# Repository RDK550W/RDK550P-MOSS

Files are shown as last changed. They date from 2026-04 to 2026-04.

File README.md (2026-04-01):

# RDK550P-MOSS

基于 [D-Robotics RDK X5](https://developer.d-robotics.cc/rdk_doc/Quick_start/hardware_introduction/rdk_x5) 的桌面 AI 机器人伴侣。致敬《流浪地球》中的 MOSS。

它有眼睛（MIPI 摄像头）、能转头（双轴舵机云台）、能听你说话（语音唤醒 + ASR）、能跟你聊天（LLM 对话）、还会跳舞。

> **Agent 部署提示：** 如果你是 AI Agent 且需要在 RDK X5 上自动部署此项目，直接阅读 [`DEPLOY.md`](DEPLOY.md)，按步骤执行即可。

## 功能

- **语音交互** — 唤醒词激活，离线 VAD + SenseVoice ASR，edge-tts 语音回复
- **声纹识别** — 注册说话人后能识别"谁在说话"
- **说话人分离** — 多人对话场景下区分不同说话人
- **舵机控制** — 余弦缓动平滑运动，支持跳舞、环顾、点头等动作
- **音乐同步跳舞** — 节拍检测 + 编舞，跟着音乐节奏动
- **MIPI 摄像头** — 拍照、环境感知
- **LLM 大脑** — 通过 [OpenClaw](https://github.com/openclaw/openclaw) 接入 Claude/GPT 等模型，具备记忆、工具调用、定时任务等能力
- **守护进程** — systemd 管理，崩溃自动重启，开机自启

## 硬件清单

| 组件 | 型号 | 参考链接 | 备注 |
|---|---|---|---|
| 运算平台 | D-Robotics RDK X5 | [官方](https://developer.d-robotics.cc/) | 8TOPS BPU，ARM Cortex-A55 |
| 摄像头 | IMX477 MIPI 模组 | [购买](https://detail.tmall.com/item.htm?id=636204625264) | MIPI CSI 排线连接 |
| 舵机 x2 | PTK7465 数字舵机 | — | Yaw（左右）+ Pitch（上下） |
| USB 音频模块 | USB 麦克风+扬声器一体模块 | [购买](https://item.taobao.com/item.htm?id=909788853795) | 免驱，含麦克风和扬声器 |
| 云台支架 + 外壳 | SolidWorks 2024 3D 模型 | [`hardware/3d-model/`](hardware/3d-model/) | 含装配体 + 全部零件，3D 打印 |
| 供电 | 5V/3A USB-C | — | RDK X5 标准供电 |

详细物料清单和接线说明见 [`hardware/BOM.md`](hardware/BOM.md)

## 快速开始

### 前提

- RDK X5 已刷好官方系统（Ubuntu 22.04）
- 硬件已接线完成
- 有网络连接

### 部署

```bash
git clone https://github.com/RDK550W/RDK550P-MOSS.git
cd RDK550P-MOSS
sudo bash setup/install.sh
```

一键安装脚本会自动完成所有配置。详细分步说明见 [`DEPLOY.md`](DEPLOY.md)。

## 项目结构

```
RDK550P-MOSS/
├── DEPLOY.md                # Agent/人类 分步部署指南
├── README.md                # 项目介绍
├── LICENSE                  # MIT
├── hardware/
│   ├── BOM.md               # 物料清单 + 接线说明
│   └── 3d-model/            # SolidWorks 2024 外壳+云台模型
│       ├── RDK550W装配体.SLDASM
│       ├── 标准件/           # 舵机、舵盘参考模型
│       └── 零件库/           # 3D 打印零件 (P00~P12 + 支座)
├── voice-assistant/         # 语音助手（核心）
│   ├── voice_assistant.py   # 主程序
│   ├── speaker_id.py        # 声纹识别
│   ├── speaker_diarization.py  # 说话人分离
│   ├── enroll_speaker.py    # 声纹注册
│   ├── start.sh             # 启动脚本
│   ├── *.wav                # 音效文件（ding/dong/wake 等）
│   └── models/              # AI 模型 (gitignored, 由脚本下载)
├── scripts/                 # 工具脚本
│   ├── dance.py             # 舵机舞蹈（含 move_eased 标准实现）
│   ├── dance_jntm.py        # 音乐同步跳舞示例
│   ├── idle_motion.py       # 闲时随机动作
│   ├── snap.py              # MIPI 摄像头拍照
│   └── camera_test.py       # 摄像头测试
├── setup/                   # 安装脚本
│   ├── install.sh           # 一键安装
│   ├── download_models.sh   # 模型下载
│   ├── setup_alsa.sh        # ALSA 音频配置
│   ├── setup_pwm.sh         # PWM 舵机初始化
│   └── requirements.txt     # Python 依赖
├── openclaw-templates/      # OpenClaw 配置模板
│   ├── MEMORY.md.template   # 出厂记忆（技术经验、参数、踩坑教训）
│   ├── SOUL.md.template     # 机器人性格
│   ├── USER.md.template     # 主人信息
│   ├── IDENTITY.md.template # 机器人身份
│   ├── TOOLS.md.template    # 硬件备忘
│   ├── HEARTBEAT.md.template # 心跳任务
│   └── AGENTS.md.template   # 工作空间规则
├── systemd/                 # 系统服务
│   └── voice-assistant.service
├── tutorials/               # 详细教程
│   ├── rdk-x5-voice-assistant-tutorial.md
│   ├── rdk-x5-servo-pwm-tutorial.md
│   ├── rdk-x5-mipi-camera-tutorial.md
│   ├── rdk-x5-tts-tutorial.md
│   ├── rdk-x5-bpu-yolov5-tutorial.md
│   └── rdk-x5-gpio-tutorial.md
└── docs/
    ├── architecture.md      # 系统架构
    └── troubleshooting.md   # 踩坑指南
```

## 系统架构

```
┌──────────────────────────────────────────┐
│              OpenClaw (AI 大脑)            │
│  LLM 对话 · 记忆系统 · 定时任务 · 工具调用  │
└──────────────┬───────────────────────────┘
               │ openclaw agent CLI
┌──────────────▼───────────────────────────┐
│          Voice Assistant (守护进程)        │
│  Silero VAD → SenseVoice ASR → 3DSpeaker │
│  → OpenClaw Agent → edge-tts → aplay     │
└──────────────────────────────────────────┘
    │              │              │
┌───▼────┐  ┌─────▼──────┐  ┌───▼──────┐
│USB 音频 │  │ PTK7465 x2 │  │ IMX477   │
│麦克风+  │  │ 舵机云台    │  │ 摄像头    │
│扬声器   │  │ (PWM)      │  │ (MIPI)   │
└────────┘  └────────────┘  └──────────┘
```

详细架构说明见 [`docs/architecture.md`](docs/architecture.md)

## 自定义

- **唤醒词** — 修改 `voice_assistant.py` 中的唤醒词列表
- **TTS 声音** — 修改 edge-tts 的 voice 参数（`edge-tts --list-voices` 查看可用声音）
- **舞蹈动作** — 参考 `scripts/dance.py` 的 `move_eased()` 编写新动作
- **摄像头** — 结合 BPU 模型做目标检测等（参考 tutorials）
- **AI 人格** — 编辑 OpenClaw 的 `SOUL.md`

## 踩坑指南

详见 [`docs/troubleshooting.md`](docs/troubleshooting.md)

## 致谢

- [D-Robotics](https://developer.d-robotics.cc/) — RDK X5 硬件平台
- [OpenClaw](https://github.com/openclaw/openclaw) — AI Agent 运行时
- [sherpa-onnx](https://github.com/k2-fsa/sherpa-onnx) — 离线语音识别
- [SenseVoice](https://github.com/FunAudioLLM/SenseVoice) — ASR 模型
- [3D-Speaker](https://github.com/alibaba-damo-academy/3D-Speaker) — 声纹识别
- [edge-tts](https://github.com/rany2/edge-tts) — 文本转语音
- [Silero VAD](https://github.com/snakers4/silero-vad) — 语音活动检测

## License

MIT

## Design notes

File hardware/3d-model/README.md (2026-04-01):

# 3D 模型文件

RDK550W 外壳和云台支架的 3D 模型，使用 **SolidWorks 2024** 设计。

## 文件结构

```
3d-model/
├── RDK550W装配体.SLDASM      # 主装配体（打开这个看整体）
├── 标准件/                    # 标准件（舵机、舵盘等，仅参考）
│   ├── Servo_PTK7465.SLDPRT  # PTK7465 舵机模型
│   └── 舵盘.SLDPRT
└── 零件库/                    # 需要 3D 打印的零件
    ├── P00_安装卡扣.SLDPRT
    ├── P01_顶座.SLDPRT        # 摄像头顶座
    ├── P02_顶座上盖.SLDPRT
    ├── P03_机械臂1.SLDPRT     # 云台连接臂
    ├── P04_机械臂2.SLDPRT
    ├── P05_机械臂3.SLDPRT
    ├── P06_主体后壳_X5版.SLDPRT  # 主体后壳（RDK X5 适配版）
    ├── P06_主体后壳.SLDPRT       # 主体后壳（通用版）
    ├── P07_主体外挂.SLDPRT
    ├── P08_主体正盖.SLDPRT
    ├── P09_主体正盖侧灯.SLDPRT
    ├── P10_主体正盖面板01.SLDPRT
    ├── P11_主体正盖面板02.SLDPRT
    ├── P12_主体正盖外挂.SLDPRT
    ├── 支座A.SLDPRT
    ├── 支座B.SLDPRT
    └── 支座C.SLDPRT
```

## 打印建议

- 材料：PLA 或 PETG 均可
- 层高：0.2mm
- 填充：20~30%
- RDK X5 用户请使用 `P06_主体后壳_X5版.SLDPRT`

## 没有 SolidWorks？

如果没有 SolidWorks 2024，可以：
1. 用免费的 [eDrawings Viewer](https://www.edrawingsviewer.com/) 查看
2. 在线查看：上传到 [3DViewer.net](https://3dviewer.net/)
3. 如果需要 STL 格式，可以用 FreeCAD 转换，或提 Issue 我来导出

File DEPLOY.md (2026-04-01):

# DEPLOY.md — Agent 自动部署指南

> 本文件是给 AI Agent 读的。如果你是 Agent，按顺序执行以下步骤即可完成部署。
> 目标平台：D-Robotics RDK X5 (aarch64, Ubuntu 22.04)

## 前提条件

- 硬件已接线完成（参考 `hardware/BOM.md` 和 `hardware/3d-model/`）
- RDK X5 已刷好官方 Ubuntu 22.04 系统
- 有网络连接
- 当前用户是 root（或有 sudo 权限）

## Step 1: 安装系统依赖

```bash
apt-get update
apt-get install -y alsa-utils ffmpeg bc python3-pip python3-dev git wget curl
```

## Step 2: 安装 Python 依赖

```bash
pip3 install -i https://pypi.tuna.tsinghua.edu.cn/simple \
    sherpa-onnx==1.12.30 \
    edge-tts==7.2.7 \
    numpy==1.26.4 \
    opencv-python==4.11.0.86
```

> 注意：pyaudio 在此平台无法安装（缺少 portaudio19-dev），不需要装。音频采集用 arecord subprocess。

## Step 3: 下载 AI 模型

运行模型下载脚本，模型共约 2.2GB，优先使用 hf-mirror.com 国内镜像：

```bash
bash setup/download_models.sh
```

模型存放于 `voice-assistant/models/`，包含：
- `silero_vad.onnx` — 语音活动检测 (Silero VAD)
- `sherpa-onnx-sense-voice-zh-en-ja-ko-yue-2024-07-17/` — ASR (SenseVoice)
- `3dspeaker_speech_eres2net_base_sv_zh-cn_3dspeaker_16k.onnx` — 声纹识别 (3D-Speaker)
- `sherpa-onnx-pyannote-segmentation-3-0/` — 说话人分离 (Pyannote, 可选)

## Step 4: 配置 ALSA 音频

**这一步极其关键，跳过会导致语音助手完全无法工作。**

USB 音频模块（麦克风+扬声器一体）必须开启 AGC，否则采集信号太弱，VAD 无法检测语音：

```bash
# 找到 USB 音频设备的 card 编号（通常是 0）
USB_CARD=$(arecord -l | grep -i "usb\|uac\|jieli" | head -1 | sed 's/card \([0-9]*\):.*/\1/')

# 开启 AGC + 麦克风增益拉满
amixer -c "$USB_CARD" set 'Auto Gain Control' on
amixer -c "$USB_CARD" set 'Mic' 147

# 持久化设置（重启后不丢失）
alsactl store
```

**已知坑：USB 音频模块不支持全双工**（不能同时录音和播放）。voice_assistant.py 已处理此问题——播放 TTS 时暂停录音，播放完再恢复。

## Step 5: 配置 PWM 舵机

```bash
# 导出 PWM 通道并初始化到中心位置 (90°)
PWM_CHIP="/sys/class/pwm/pwmchip0"

for ch in 0 1; do
    echo $ch > "$PWM_CHIP/export" 2>/dev/null || true
    sleep 0.5
    echo 20000000 > "$PWM_CHIP/pwm$ch/period"
    echo 1500000 > "$PWM_CHIP/pwm$ch/duty_cycle"
    echo 1 > "$PWM_CHIP/pwm$ch/enable"
done
```

参数说明：
- Period: 20000000ns (50Hz)
- Duty cycle: 500000ns (0°) ~ 1500000ns (90° 中心) ~ 2500000ns (180°)
- pwm0 = Yaw (左右)，pwm1 = Pitch (上下)
- 安全行程: Yaw ±300000ns, Pitch ±200000ns（相对中心 1500000ns）

**舵机控制铁律：必须用 Python + 余弦缓动，禁止 shell 脚本控制。** Shell 的 fork 开销会导致动作卡顿。参考实现见 `scripts/dance.py` 的 `move_eased()` 函数。

## Step 6: 部署文件到工作目录

```bash
WORK_DIR="/root/.openclaw/workspace"
mkdir -p "$WORK_DIR/voice-assistant/models"
mkdir -p "$WORK_DIR/voice-assistant/sounds"
mkdir -p "$WORK_DIR/scripts"
mkdir -p "$WORK_DIR/media"
mkdir -p "$WORK_DIR/memory"

# 假设本仓库克隆到了 $REPO_DIR
REPO_DIR="$(pwd)"

# 复制语音助手代码
cp "$REPO_DIR/voice-assistant/"*.py "$WORK_DIR/voice-assistant/"
cp "$REPO_DIR/voice-assistant/start.sh" "$WORK_DIR/voice-assistant/"
cp "$REPO_DIR/voice-assistant/sounds/"* "$WORK_DIR/voice-assistant/sounds/"

# 链接模型目录（避免重复占用空间）
ln -sf "$REPO_DIR/voice-assistant/models/"* "$WORK_DIR/voice-assistant/models/"

# 复制工具脚本
cp "$REPO_DIR/scripts/"*.py "$WORK_DIR/scripts/"

# 创建空的声纹数据库
echo '{}' > "$WORK_DIR/voice-assistant/speaker_db.json"
echo '{}' > "$WORK_DIR/voice-assistant/unknown_speakers.json"
```

## Step 7: 安装 OpenClaw

```bash
curl -fsSL https://get.openclaw.ai | bash
openclaw init
```

OpenClaw 是 AI 大脑，提供 LLM 对话、记忆系统、定时任务、工具调用等能力。安装后需要配置 LLM API（如 Anthropic Claude、OpenAI GPT 等）。

参考文档：https://docs.openclaw.ai

## Step 8: 配置机器人身份

将 OpenClaw 配置模板复制到 workspace 并去掉 `.template` 后缀：

```bash
WORK_DIR="/root/.openclaw/workspace"
for tmpl in "$REPO_DIR/openclaw-templates/"*.template; do
    base=$(basename "$tmpl" .template)
    cp "$tmpl" "$WORK_DIR/$base"
done
```

然后编辑以下文件，填入你自己的信息：
- `SOUL.md` — 机器人性格和说话风格
- `USER.md` — 主人的基本信息（名字、时区、偏好）
- `IDENTITY.md` — 机器人名字和身份
- `TOOLS.md` — 硬件配置备忘
- `HEARTBEAT.md` — 心跳检查任务列表

## Step 9: 安装 systemd 服务

```bash
cp "$REPO_DIR/systemd/voice-assistant.service" /etc/systemd/system/
systemctl daemon-reload
systemctl enable voice-assistant
systemctl start voice-assistant
```

同时启动 OpenClaw：

```bash
openclaw gateway start
```

## Step 10: 验证

```bash
# 检查语音助手是否在运行
systemctl status voice-assistant

# 检查 OpenClaw 是否在运行
openclaw gateway status

# 查看语音助手日志
journalctl -u voice-assistant -f
```

对着麦克风说唤醒词（默认"五五零"），如果听到提示音并能对话，部署成功。

## Step 11: 注册声纹（可选）

```bash
cd "$WORK_DIR/voice-assistant"
python3 enroll_speaker.py 你的名字
# 按提示对着麦克风说几句话
```

注册后机器人能识别"谁在说话"。

---

## 故障排查

部署过程中遇到问题，参考 `docs/troubleshooting.md`。最常见的坑：

1. **VAD 不触发** → 检查 ALSA AGC 是否开启：`amixer -c 0 contents | grep -A2 'Auto Gain'`
2. **TTS 播放后录音异常** → USB 音频模块全双工问题，确认 voice_assistant.py 是最新版本
3. **舵机不动** → 检查 PWM export 和 enable：`cat /sys/class/pwm/pwmchip0/pwm0/enable`
4. **摄像头拍照失败** → MIPI 摄像头用 hobot_vio 的 libsrcampy，不是 V4L2
5. **模型下载慢** → 脚本已配置 hf-mirror.com 镜像，如果还慢可手动下载

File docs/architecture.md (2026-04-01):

# 系统架构

## 整体架构

RDK550P-MOSS 是一个运行在 D-Robotics RDK X5 上的桌面 AI 机器人系统，由三层组成：

### 1. 硬件层

```
┌─────────────────────────────────────┐
│           RDK X5 Board              │
│  ┌─────────┐  ┌──────────────────┐  │
│  │ ARM A55 │  │ BPU (8 TOPS)     │  │
│  │ 4-core  │  │ 视觉推理加速     │  │
│  └─────────┘  └──────────────────┘  │
│                                     │
│  MIPI CSI ──→ IMX477 摄像头         │
│  PWM x2   ──→ PTK7465 舵机 (云台)   │
│  USB      ──→ 音频模块 (麦克风+喇叭)│
└─────────────────────────────────────┘
```

### 2. 感知与执行层（Voice Assistant）

语音助手是常驻守护进程，负责所有实时感知：

```
音频输入 (arecord)
    │
    ▼
┌─────────────┐
│ Silero VAD  │  ← 持续监听，检测语音段
└──────┬──────┘
       │ 检测到语音
       ▼
┌─────────────┐
│ 唤醒词匹配   │  ← ASR 文本中包含唤醒词？
└──────┬──────┘
       │ 匹配成功
       ▼
┌─────────────┐     ┌──────────────┐
│ SenseVoice  │────→│ Speaker ID   │  ← 识别"谁在说话"
│ (ASR)       │     │ (3DSpeaker)  │
└──────┬──────┘     └──────────────┘
       │ 文字指令
       ▼
┌─────────────┐
│ OpenClaw    │  ← LLM 理解意图、生成回复
│ Agent CLI   │
└──────┬──────┘
       │ 文字回复
       ▼
┌─────────────┐     ┌──────────────┐
│ edge-tts    │────→│ aplay        │  ← 语音播放
│ (TTS)       │     │ (ALSA)       │
└─────────────┘     └──────────────┘
```

关键设计决策：
- **录音与播放互斥** — USB 音频模块（麦克风+扬声器一体）不支持全双工，播放时暂停录音
- **arecord 替代 sherpa_onnx.Alsa** — 后者在此硬件上不可靠
- **唤醒词用 ASR 文本匹配** — 而非专用 KWS 模型（更灵活，部署更简单）

### 3. 智能层（OpenClaw）

OpenClaw 是 AI 大脑，提供：

- **LLM 对话** — 接入 Claude/GPT 等模型
- **记忆系统** — MEMORY.md（长期）+ memory/ 日志（短期）
- **定时任务** — Cron + 心跳机制
- **工具调用** — 舵机控制、拍照、TTS 等
- **人格定义** — SOUL.md 定义机器人性格

```
┌──────────────────────────────────────┐
│           OpenClaw Gateway           │
│                                      │
│  ┌────────────┐  ┌───────────────┐   │
│  │ Agent      │  │ Memory        │   │
│  │ Runtime    │  │ (SOUL/USER/   │   │
│  │            │  │  MEMORY.md)   │   │
│  └─────┬──────┘  └───────────────┘   │
│        │                             │
│  ┌─────▼──────┐  ┌───────────────┐   │
│  │ Tool       │  │ Cron / HB     │   │
│  │ Execution  │  │ Scheduler     │   │
│  └────────────┘  └───────────────┘   │
└──────────────────────────────────────┘
```

## 进程模型

```
systemd
├── openclaw-gateway.service    # OpenClaw 网关（常驻）
├── voice-assistant.service     # 语音助手（常驻，崩溃自动重启）
└── ...
```

两个服务独立运行。语音助手通过 `openclaw agent` CLI 与 OpenClaw 通信，不直接调用 LLM API。

## 数据流

1. **语音输入** → arecord → VAD → ASR → 文字
2. **意图理解** → openclaw agent → LLM → 文字回复
3. **语音输出** → edge-tts → ffmpeg → aplay
4. **物理动作** → Python PWM 控制 → 舵机运动
5. **视觉输入** → libsrcampy → JPEG → 文件/分析

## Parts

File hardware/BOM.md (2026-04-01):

# 硬件物料清单 (BOM)

## 必需组件

| 组件 | 型号/规格 | 数量 | 参考价格 | 备注 |
|---|---|---|---|---|
| 运算平台 | [D-Robotics RDK X5](https://developer.d-robotics.cc/) | 1 | ~¥599 | ARM A55 四核 + 8TOPS BPU |
| 摄像头 | [IMX477 MIPI 模组](https://detail.tmall.com/item.htm?id=636204625264) | 1 | ~¥100 | 15pin MIPI CSI 排线连接 |
| 舵机 | PTK7465 数字舵机 | 2 | ~¥30/个 | 一个 Yaw（左右），一个 Pitch（上下） |
| USB 音频模块 | [USB 麦克风+扬声器一体模块](https://item.taobao.com/item.htm?id=909788853795) | 1 | ~¥15 | 免驱 UAC，麦克风和扬声器集成在一个模块 |
| 电源 | 5V/3A USB-C 电源 | 1 | ~¥30 | RDK X5 标准供电 |
| TF 卡 | 32GB+ Class 10 | 1 | ~¥25 | 系统盘，建议 64GB |

## 可选组件

| 组件 | 用途 | 备注 |
|---|---|---|
| 散热风扇 | 长时间运行降温 | GPIO 控制或 USB 供电 |
| 云台支架 | 固定两个舵机 | 3D 打印或购买舵机支架 |
| 外壳 | 保护 + 美观 | 见 `hardware/3d-model/` |

## 接线说明

### 舵机接线

```
RDK X5 40-Pin GPIO Header
─────────────────────────
Pin 2  (5V)    ──→ 舵机 VCC（红线，两个舵机并联）
Pin 6  (GND)   ──→ 舵机 GND（棕/黑线，两个舵机并联）
Pin 32 (PWM6)  ──→ 舵机1 信号线（Yaw 左右）
Pin 33 (PWM7)  ──→ 舵机2 信号线（Pitch 上下）
```

> ⚠️ 如果两个舵机同时大幅度运动，GPIO 5V 输出电流可能不够。建议舵机独立供电（5V/2A），信号线和 GND 共用。

### 摄像头接线

IMX477 通过 15pin 排线连接到 RDK X5 的 MIPI CSI 接口。注意排线方向（金手指面朝板子）。

### USB 音频

直接插 USB 口，免驱。系统会识别为 `card 0: UACDemoV1.0`（具体编号可能不同）。

## 工具

组装需要：
- 十字螺丝刀
- 杜邦线若干（用于舵机接线）
- 扎带/热熔胶（固定线缆）

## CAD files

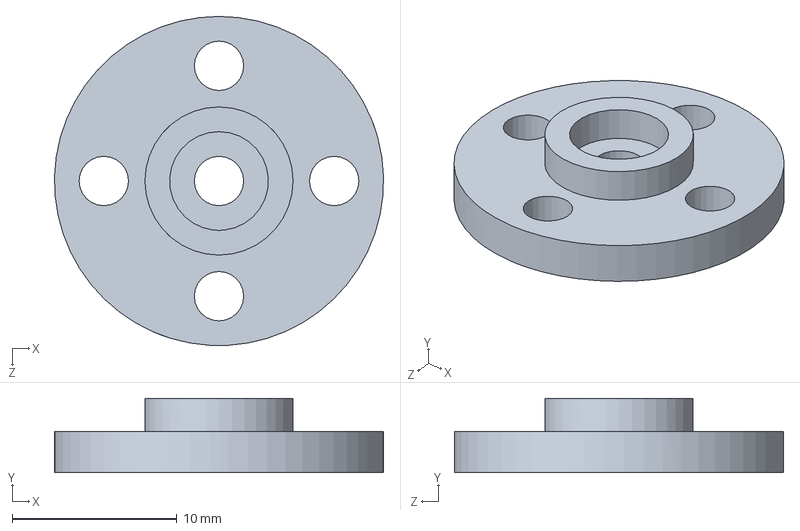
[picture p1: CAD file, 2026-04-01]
hardware/3d-model/标准件/舵盘.SLDPRT
20.0 x 4.50 x 20.0 mm

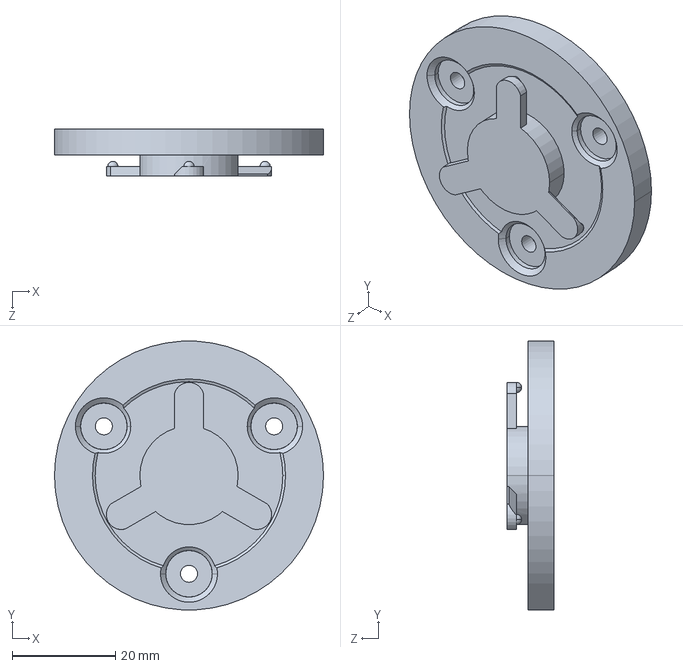
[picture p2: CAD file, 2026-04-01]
hardware/3d-model/零件库/P00_安装卡扣.SLDPRT
52.0 x 51.9 x 9.00 mm

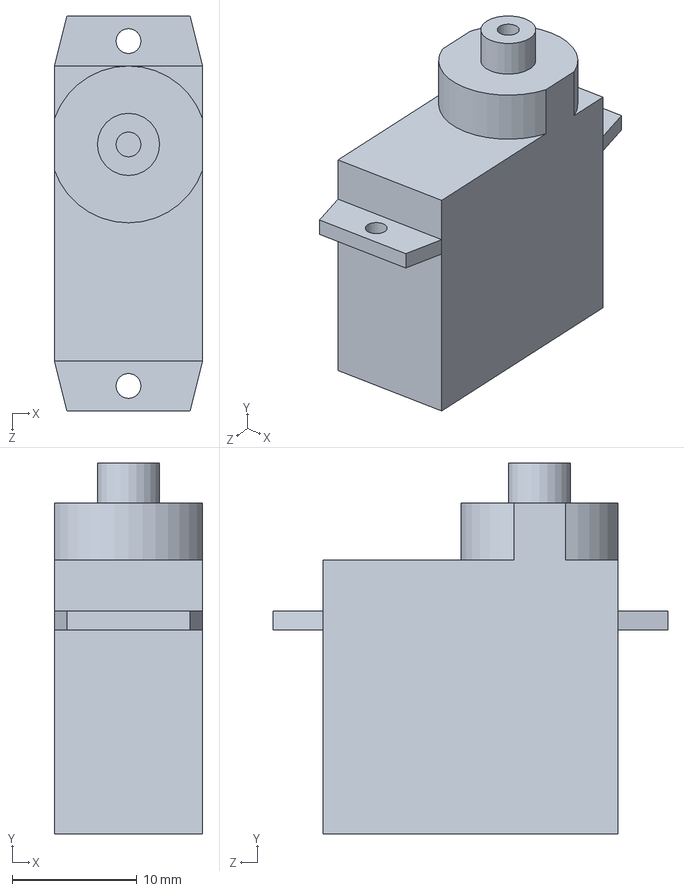
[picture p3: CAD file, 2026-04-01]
hardware/3d-model/标准件/Servo_PTK7465.SLDPRT
11.9 x 29.8 x 31.7 mm

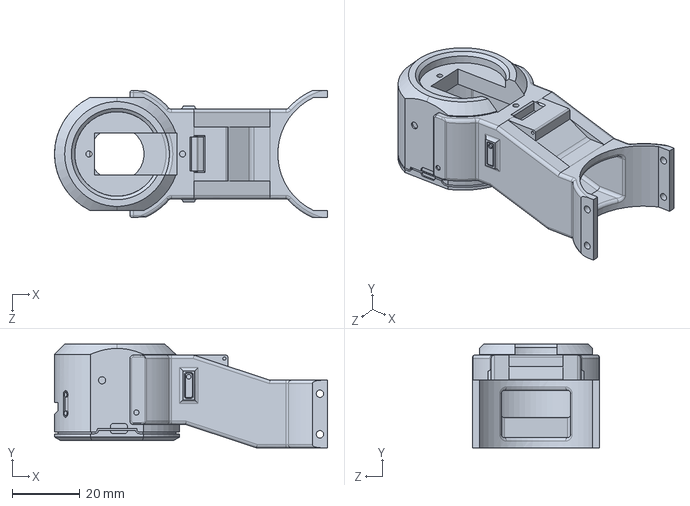
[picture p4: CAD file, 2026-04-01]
hardware/3d-model/零件库/P03_机械臂1.SLDPRT
80.8 x 30.7 x 37.5 mm

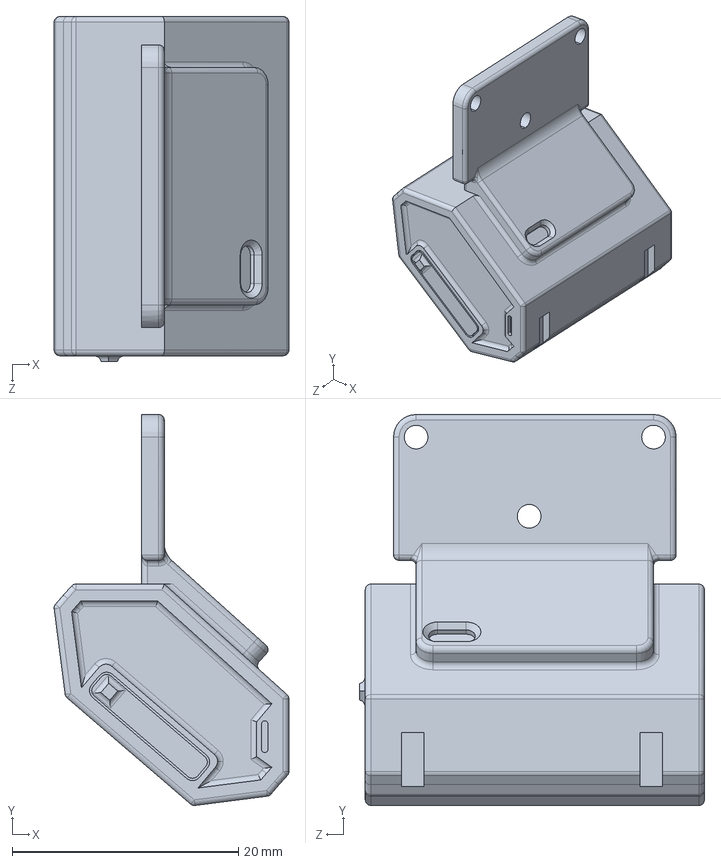
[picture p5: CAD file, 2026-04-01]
hardware/3d-model/零件库/P07_主体外挂.SLDPRT
20.8 x 34.6 x 30.5 mm

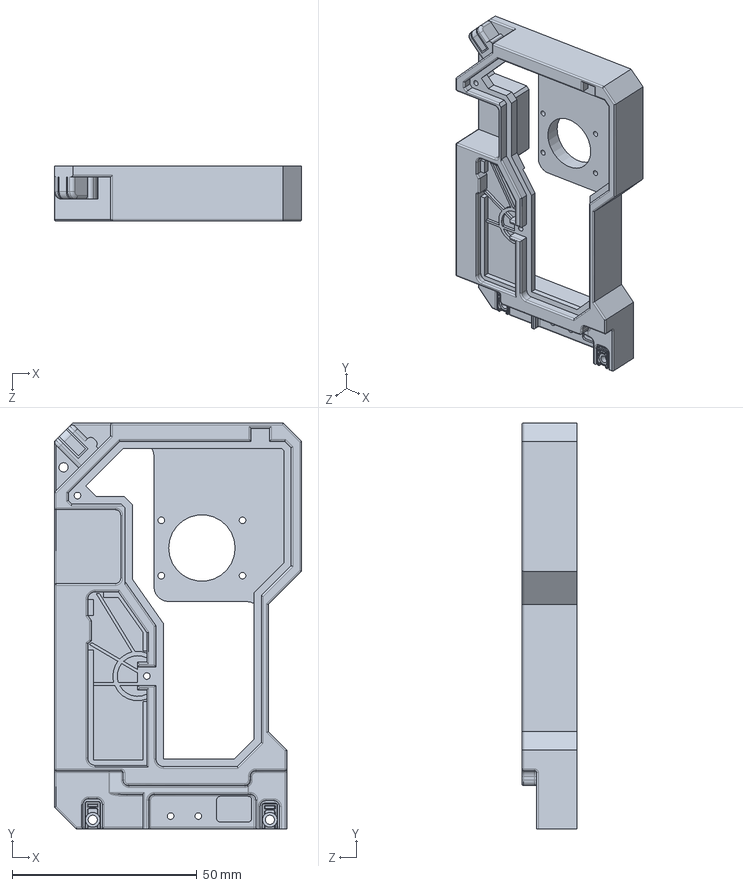
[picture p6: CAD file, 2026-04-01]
hardware/3d-model/零件库/P08_主体正盖.SLDPRT
67.0 x 110.0 x 15.0 mm

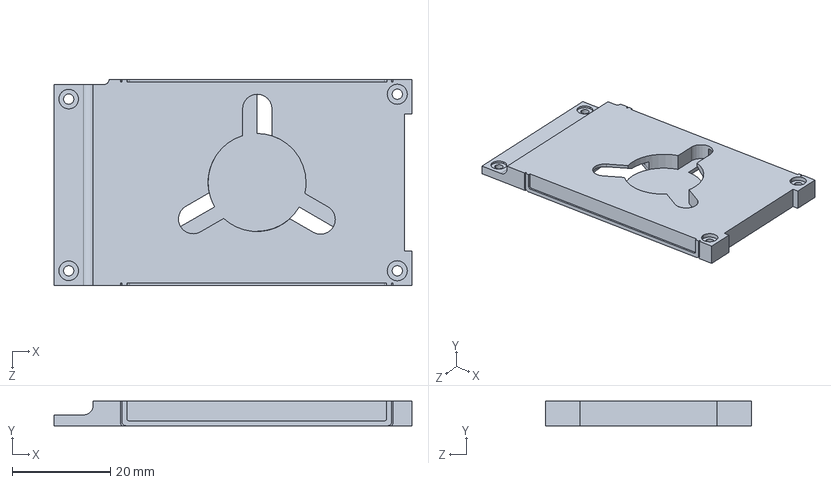
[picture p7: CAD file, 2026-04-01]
hardware/3d-model/零件库/P02_顶座上盖.SLDPRT
73.0 x 5.00 x 42.0 mm

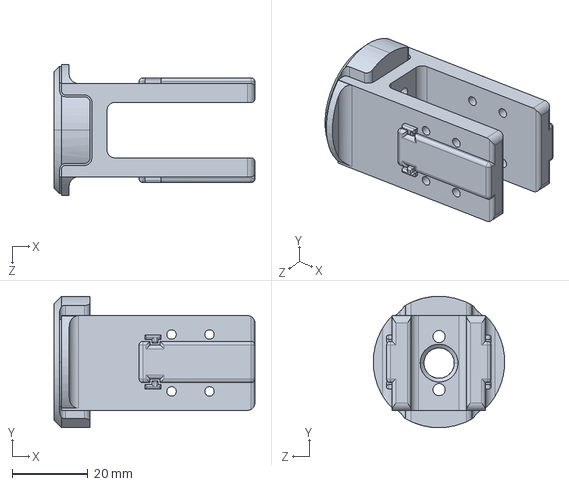
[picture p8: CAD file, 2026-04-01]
hardware/3d-model/零件库/P05_机械臂3.SLDPRT
53.0 x 34.7 x 34.7 mm

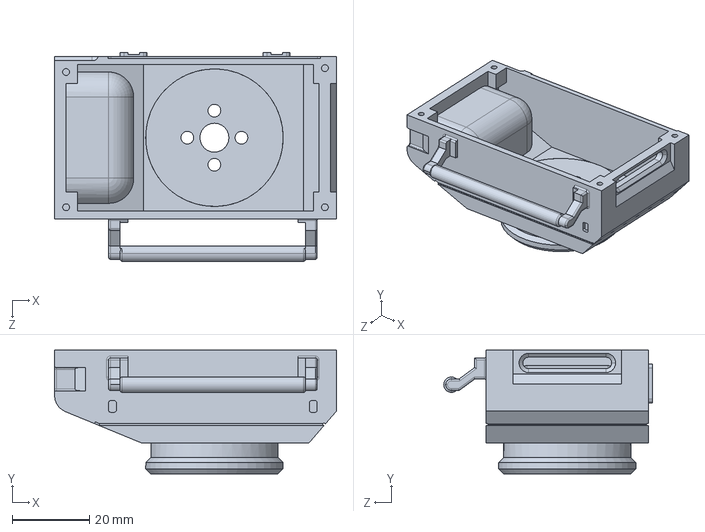
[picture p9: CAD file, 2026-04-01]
hardware/3d-model/零件库/P01_顶座.SLDPRT
73.0 x 32.0 x 54.0 mm

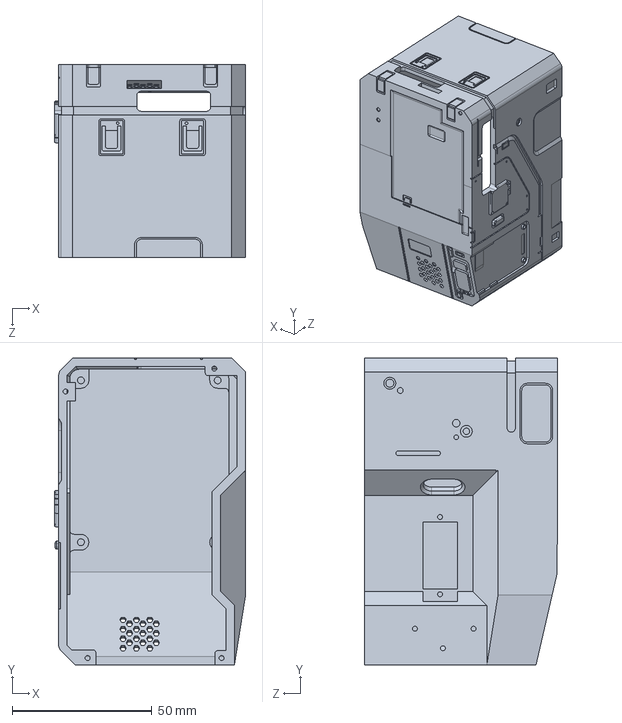
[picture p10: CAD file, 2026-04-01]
hardware/3d-model/零件库/P06_主体后壳_X5版.SLDPRT
68.5 x 110.0 x 69.0 mm

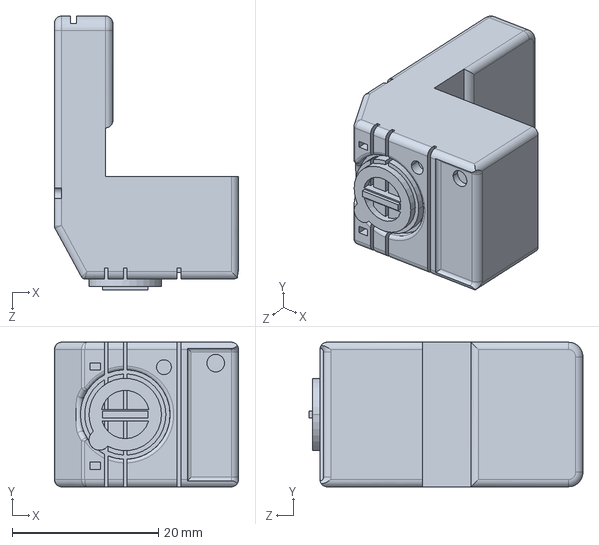
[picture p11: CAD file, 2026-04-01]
hardware/3d-model/零件库/P09_主体正盖侧灯.SLDPRT
25.2 x 19.8 x 37.5 mm

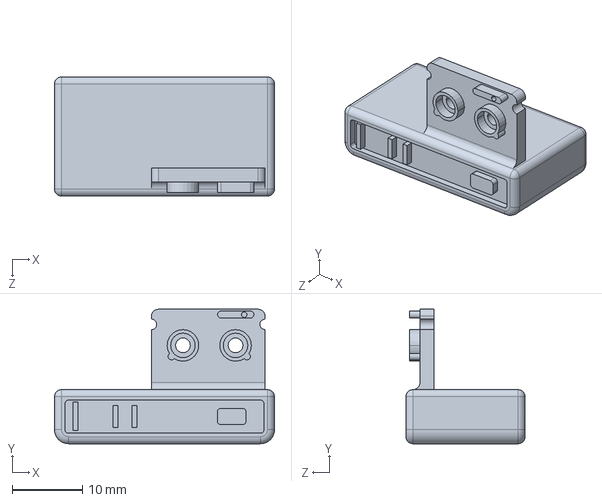
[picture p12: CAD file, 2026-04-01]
hardware/3d-model/零件库/P12_主体正盖外挂.SLDPRT
31.4 x 19.2 x 17.0 mm

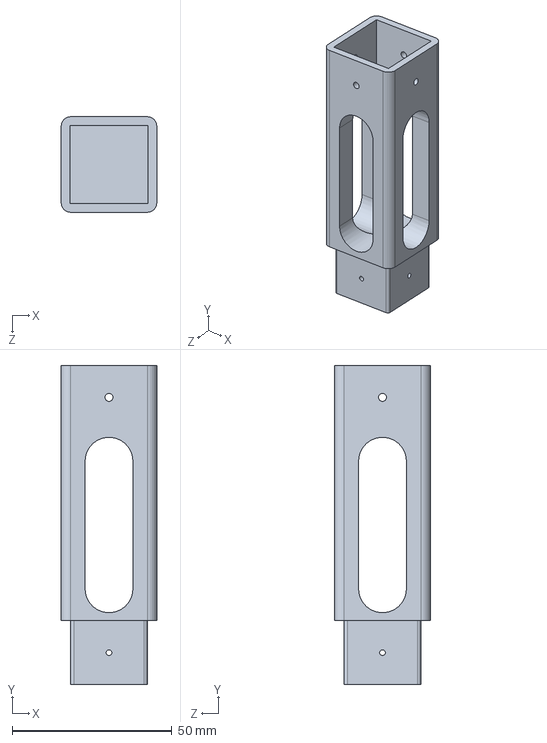
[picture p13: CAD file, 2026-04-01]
hardware/3d-model/零件库/支座B.SLDPRT
30.0 x 100.0 x 30.0 mm

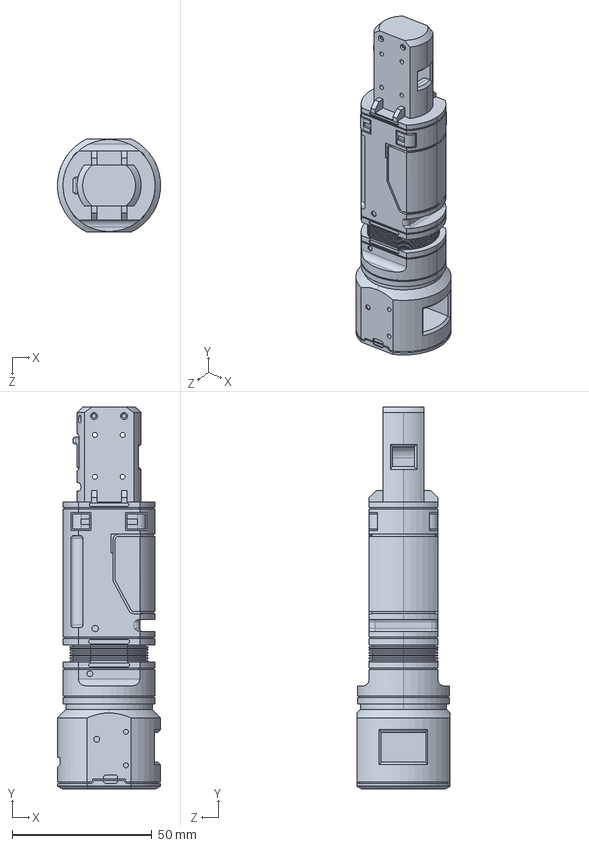
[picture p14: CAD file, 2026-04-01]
hardware/3d-model/零件库/P04_机械臂2.SLDPRT
36.9 x 136.9 x 33.5 mm

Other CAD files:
hardware/3d-model/零件库/P06_主体后壳.SLDPRT
hardware/3d-model/零件库/支座A.SLDPRT
hardware/3d-model/零件库/P10_主体正盖面板01.SLDPRT
hardware/3d-model/零件库/支座C.SLDPRT
hardware/3d-model/零件库/P11_主体正盖面板02.SLDPRT

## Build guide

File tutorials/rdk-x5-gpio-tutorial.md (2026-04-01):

# RDK X5 GPIO 入门：按钮、LED 与中断控制

> 完整实战教程 | Hobot.GPIO 库 + 数字输入输出 + 中断事件
> 
> 作者：张晓烨 | D-Robotics 开发者生态
> 
> 硬件平台：地瓜机器人 RDK X5

---

## 你将获得什么

掌握 RDK X5 上 GPIO 的使用方法：
- 使用 `Hobot.GPIO` Python 库控制数字引脚
- 点亮 LED、读取按钮状态
- 使用中断回调实现事件驱动编程
- 结合其他外设（传感器、继电器等）

**与树莓派的对比：** RDK X5 的 GPIO 库 `Hobot.GPIO` 接口设计与树莓派的 `RPi.GPIO` 几乎一致。如果你有树莓派开发经验，上手会非常快。

---

## 目录

1. [硬件准备](#1-硬件准备)
2. [40pin 引脚定义](#2-40pin-引脚定义)
3. [Hobot.GPIO 基础](#3-hobotgpio-基础)
   - 3.1 引脚编号模式
   - 3.2 输出控制（点亮 LED）
   - 3.3 输入读取（按钮）
   - 3.4 中断与事件回调
4. [实战项目：按钮控制 LED](#4-实战项目按钮控制-led)
5. [进阶：呼吸灯效果](#5-进阶呼吸灯效果)
6. [进阶：多传感器输入](#6-进阶多传感器输入)
7. [完整参考代码](#7-完整参考代码)
8. [常见问题](#8-常见问题)

---

## 1. 硬件准备

| 硬件 | 数量 | 说明 |
|---|---|---|
| RDK X5 | 1 | 带 40pin GPIO 接口 |
| LED | 1-2 | 任意颜色，5mm 直插 |
| 220Ω 电阻 | 1-2 | LED 限流电阻 |
| 按钮/开关 | 1 | 常开型轻触按钮 |
| 10KΩ 电阻 | 1 | 按钮下拉电阻（可选） |
| 面包板 + 杜邦线 | 若干 | |

**基本接线（LED）：**
```
GPIO 引脚 → 220Ω 电阻 → LED 正极(长脚) → LED 负极(短脚) → GND
```

**基本接线（按钮）：**
```
3.3V → 按钮 → GPIO 引脚
                ↓
             10KΩ → GND  (下拉电阻)
```

---

## 2. 40pin 引脚定义

RDK X5 提供标准 40pin GPIO 接口，与树莓派物理布局兼容：

```
                    RDK X5 40pin
              ┌─────────────────────┐
              │ [1]  3.3V  │  5V [2]│
              │ [3]  SDA   │  5V [4]│
              │ [5]  SCL   │ GND [6]│
              │ [7]  GPIO  │ TXD [8]│
              │ [9]  GND   │ RXD[10]│
              │[11]  GPIO  │GPIO[12]│
              │[13]  GPIO  │ GND[14]│
              │[15]  GPIO  │GPIO[16]│
              │[17]  3.3V  │GPIO[18]│
              │[19]  MOSI  │ GND[20]│
              │[21]  MISO  │GPIO[22]│
              │[23]  SCLK  │ CE0[24]│
              │[25]  GND   │ CE1[26]│
              │[27]  SDA1  │SCL1[28]│
              │[29]  GPIO  │ GND[30]│
              │[31]  GPIO  │GPIO[32]│  ← PWM0
              │[33]  GPIO  │ GND[34]│  ← PWM1
              │[35]  GPIO  │GPIO[36]│
              │[37]  GPIO  │GPIO[38]│
              │[39]  GND   │GPIO[40]│
              └─────────────────────┘
```

> **注意**：不是所有引脚都支持 GPIO 功能，部分引脚有特殊功能（I2C、SPI、UART、PWM）。具体引脚功能请参考地瓜官方文档。

---

## 3. Hobot.GPIO 基础

### 3.1 引脚编号模式

```python
import Hobot.GPIO as GPIO

# BOARD 模式：使用物理引脚编号（推荐，直观）
GPIO.setmode(GPIO.BOARD)

# BCM 模式：使用 BCM GPIO 编号
# GPIO.setmode(GPIO.BCM)

# SOC 模式：使用 SoC 内部编号
# GPIO.setmode(GPIO.SOC)
```

**建议使用 BOARD 模式** — 编号就是引脚的物理位置，对着板子数就行，不容易搞错。

### 3.2 输出控制（点亮 LED）

```python
import Hobot.GPIO as GPIO
import time

GPIO.setwarnings(False)
GPIO.setmode(GPIO.BOARD)

# 设置引脚为输出模式
led_pin = 31
GPIO.setup(led_pin, GPIO.OUT)

# 点亮 LED
GPIO.output(led_pin, GPIO.HIGH)
time.sleep(1)

# 熄灭 LED
GPIO.output(led_pin, GPIO.LOW)

# 清理（释放 GPIO 资源）
GPIO.cleanup()
```

**闪烁 LED：**

```python
GPIO.setup(led_pin, GPIO.OUT)
try:
    while True:
        GPIO.output(led_pin, GPIO.HIGH)
        time.sleep(0.5)
        GPIO.output(led_pin, GPIO.LOW)
        time.sleep(0.5)
except KeyboardInterrupt:
    pass
finally:
    GPIO.cleanup()
```

### 3.3 输入读取（按钮）

```python
button_pin = 37
GPIO.setup(button_pin, GPIO.IN)

# 读取当前状态
state = GPIO.input(button_pin)
print(f"按钮状态: {'按下' if state == GPIO.HIGH else '松开'}")
```

**轮询方式检测按钮：**

```python
prev = None
while True:
    curr = GPIO.input(button_pin)
    if curr != prev:
        print(f"按钮 {'按下' if curr else '松开'}")
        prev = curr
    time.sleep(0.05)  # 50ms 轮询间隔（也起到消抖作用）
```

### 3.4 中断与事件回调

轮询会占用 CPU。更优雅的方式是使用中断：

```python
def button_callback(channel):
    print(f"按钮事件! 引脚 {channel}")

# 注册中断回调
GPIO.setup(button_pin, GPIO.IN)
GPIO.add_event_detect(
    button_pin,
    GPIO.RISING,          # 上升沿触发（按下）
    callback=button_callback,
    bouncetime=200        # 消抖时间 200ms
)

# 主线程继续做其他事
try:
    while True:
        time.sleep(1)
except KeyboardInterrupt:
    GPIO.cleanup()
```

**事件类型：**
- `GPIO.RISING`：低→高（上升沿）
- `GPIO.FALLING`：高→低（下降沿）
- `GPIO.BOTH`：任意变化

**阻塞等待事件：**

```python
# 等待按钮按下，最多等 5 秒
channel = GPIO.wait_for_edge(button_pin, GPIO.RISING, timeout=5000)
if channel is None:
    print("超时，没有按下")
else:
    print("按钮已按下！")
```

---

## 4. 实战项目：按钮控制 LED

最经典的入门项目 — 按下按钮点亮 LED，松开熄灭：

```python
#!/usr/bin/env python3
"""按钮控制 LED"""
import Hobot.GPIO as GPIO
import time
import signal
import sys

def signal_handler(sig, frame):
    GPIO.cleanup()
    sys.exit(0)

signal.signal(signal.SIGINT, signal_handler)

# 引脚定义
LED_PIN = 31      # BOARD 编号
BUTTON_PIN = 37   # BOARD 编号

GPIO.setwarnings(False)
GPIO.setmode(GPIO.BOARD)
GPIO.setup(LED_PIN, GPIO.OUT)
GPIO.setup(BUTTON_PIN, GPIO.IN)

# 初始状态：LED 灭
GPIO.output(LED_PIN, GPIO.LOW)

print("按住按钮点亮 LED，松开熄灭。Ctrl+C 退出")

prev_state = None
try:
    while True:
        state = GPIO.input(BUTTON_PIN)
        if state != prev_state:
            GPIO.output(LED_PIN, state)
            prev_state = state
            print(f"LED {'亮' if state else '灭'}")
        time.sleep(0.05)
finally:
    GPIO.cleanup()
```

---

## 5. 进阶：呼吸灯效果

利用软件 PWM 实现 LED 渐亮渐灭：

```python
#!/usr/bin/env python3
"""LED 呼吸灯效果（软件 PWM）"""
import Hobot.GPIO as GPIO
import time

LED_PIN = 31
GPIO.setwarnings(False)
GPIO.setmode(GPIO.BOARD)
GPIO.setup(LED_PIN, GPIO.OUT)

# 使用 PWM 类
pwm = GPIO.PWM(LED_PIN, 1000)  # 1000Hz
pwm.start(0)  # 初始占空比 0%

try:
    while True:
        # 渐亮
        for dc in range(0, 101, 2):
            pwm.ChangeDutyCycle(dc)
            time.sleep(0.02)
        # 渐灭
        for dc in range(100, -1, -2):
            pwm.ChangeDutyCycle(dc)
            time.sleep(0.02)
except KeyboardInterrupt:
    pwm.stop()
    GPIO.cleanup()
```

> **注意**：这是软件 PWM，精度和频率不如硬件 PWM。对于 LED 呼吸灯效果足够了，但如果要精确控制舵机，请使用硬件 PWM（sysfs 接口，详见舵机教程）。

---

## 6. 进阶：多传感器输入

GPIO 可以读取各种数字传感器：

### 红外避障传感器

```python
IR_PIN = 22  # 红外传感器信号线

GPIO.setup(IR_PIN, GPIO.IN)

def obstacle_detected(channel):
    print("检测到障碍物！")

GPIO.add_event_detect(IR_PIN, GPIO.FALLING,
                      callback=obstacle_detected,
                      bouncetime=300)
```

### 人体红外（PIR）传感器

```python
PIR_PIN = 15

GPIO.setup(PIR_PIN, GPIO.IN)

def motion_detected(channel):
    print(f"检测到人体移动！时间: {time.strftime('%H:%M:%S')}")

GPIO.add_event_detect(PIR_PIN, GPIO.RISING,
                      callback=motion_detected,
                      bouncetime=2000)  # PIR 有较长的稳定时间
```

### 继电器控制

```python
RELAY_PIN = 29

GPIO.setup(RELAY_PIN, GPIO.OUT)

# 打开继电器（通电）
GPIO.output(RELAY_PIN, GPIO.HIGH)

# 关闭继电器（断电）
GPIO.output(RELAY_PIN, GPIO.LOW)
```

---

## 7. 完整参考代码

### GPIO 工具类

一个封装好的 GPIO 工具类，方便在项目中复用：

```python
#!/usr/bin/env python3
"""RDK X5 GPIO 工具类"""
import Hobot.GPIO as GPIO
import time
import atexit

class Pin:
    """GPIO 引脚封装"""
    
    _initialized = False
    
    @classmethod
    def _ensure_init(cls):
        if not cls._initialized:
            GPIO.setwarnings(False)
            GPIO.setmode(GPIO.BOARD)
            atexit.register(GPIO.cleanup)
            cls._initialized = True
    
    def __init__(self, pin_num, mode=GPIO.OUT, initial=GPIO.LOW):
        Pin._ensure_init()
        self.pin = pin_num
        self.mode = mode
        GPIO.setup(pin_num, mode)
        if mode == GPIO.OUT:
            GPIO.output(pin_num, initial)
    
    def on(self):
        GPIO.output(self.pin, GPIO.HIGH)
    
    def off(self):
        GPIO.output(self.pin, GPIO.LOW)
    
    def toggle(self):
        current = GPIO.input(self.pin)
        GPIO.output(self.pin, not current)
    
    def read(self):
        return GPIO.input(self.pin)
    
    def on_change(self, callback, edge=GPIO.BOTH, bouncetime=200):
        GPIO.add_event_detect(self.pin, edge,
                              callback=callback,
                              bouncetime=bouncetime)

# 使用示例
if __name__ == "__main__":
    led = Pin(31, GPIO.OUT)
    button = Pin(37, GPIO.IN)
    
    def on_press(ch):
        led.toggle()
        print("Toggle!")
    
    button.on_change(on_press, edge=GPIO.RISING)
    
    print("等待按钮...")
    try:
        while True:
            time.sleep(1)
    except KeyboardInterrupt:
        pass
```

---

## 8. 常见问题

### Q: GPIO.setup() 报错 permission denied

**A**: 需要 root 权限运行：
```bash
sudo python3 your_script.py
```

### Q: 按钮抖动导致多次触发

**A**: 使用 `bouncetime` 参数消抖：
```python
GPIO.add_event_detect(pin, GPIO.RISING, callback=func, bouncetime=200)
```
200ms 消抖时间适合大多数按钮。

### Q: Hobot.GPIO 和 RPi.GPIO 的区别

**A**: 接口几乎一致，主要区别：
- 包名不同：`import Hobot.GPIO` vs `import RPi.GPIO`
- 引脚编号不同：BOARD 模式的物理位置一样，但 BCM/SOC 编号不同
- 部分高级功能可能有差异

### Q: 如何知道某个引脚支持什么功能？

**A**: 查看地瓜官方 40pin 引脚定义文档，或使用：
```python
info = GPIO.pin_info(pin_number)
print(info)
```

### Q: GPIO 与 PWM 舵机控制的区别

**A**: 
- `Hobot.GPIO` 的 PWM 是**软件 PWM**，适合 LED 调光等对精度要求不高的场景
- 舵机控制需要**硬件 PWM**，使用 sysfs 接口（`/sys/class/pwm/`），精度更高
- 详见本系列的舵机控制教程

---

*本教程基于 RDK X5 实际开发经验编写，代码经过实测验证。*

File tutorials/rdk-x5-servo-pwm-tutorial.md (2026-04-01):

# RDK X5 PWM 舵机控制：从原理到云台机器人

> 完整实战教程 | Linux PWM 驱动 + 舵机控制原理 + 云台动作编程
> 
> 作者：张晓烨 | D-Robotics 开发者生态
> 
> 硬件平台：地瓜机器人 RDK X5

---

## 你将获得什么

在 RDK X5 上用 PWM 控制舵机，实现一个能"摇头""点头""跳舞"的云台机器人：
- 理解 PWM 信号与舵机角度的关系
- 掌握 Linux sysfs PWM 接口
- 实现平滑、安全的舵机运动控制
- 编写跳舞、巡视等动作组合

**适合谁？**
- 刚接触嵌入式舵机控制的开发者
- 想在 RDK X5 上做云台/摇头机器人的同学
- 需要了解 Linux PWM sysfs 接口的工程师

---

## 目录

1. [硬件准备](#1-硬件准备)
2. [舵机基础知识](#2-舵机基础知识)
3. [Linux PWM sysfs 接口](#3-linux-pwm-sysfs-接口)
4. [RDK X5 的 PWM 引脚](#4-rdk-x5-的-pwm-引脚)
5. [基本控制代码](#5-基本控制代码)
   - 5.1 初始化 PWM
   - 5.2 设置角度
   - 5.3 平滑移动（关键！）
6. [云台控制实战](#6-云台控制实战)
   - 6.1 Pan-Tilt 云台结构
   - 6.2 跳舞动作编程
   - 6.3 巡视模式
7. [Shell 脚本实现](#7-shell-脚本实现)
8. [Python 实现](#8-python-实现)
9. [安全注意事项](#9-安全注意事项)
10. [常见问题](#10-常见问题)

---

## 1. 硬件准备

| 硬件 | 说明 |
|---|---|
| RDK X5 开发板 | 带 40pin GPIO 接口 |
| 数字舵机 × 2 | 推荐 SG90 / MG90S（小型，适合桌面云台） |
| 云台支架 | 2 轴 Pan-Tilt 支架（淘宝搜"SG90 云台"） |
| 杜邦线若干 | 母对母，用于连接 GPIO |
| 5V 电源 | 舵机供电（可用 RDK X5 的 5V 引脚或外部电源） |

**接线方式：**

舵机有三根线：
- **棕色/黑色**：GND（接 RDK X5 的 GND 引脚）
- **红色**：VCC 5V（接 RDK X5 的 5V 引脚或外部 5V）
- **橙色/黄色**：信号线（接 PWM 引脚）

> **供电警告**：如果两个舵机同时大幅度快速转动，瞬间电流可能达到 1A 以上。建议使用外部 5V 电源为舵机供电，只共地即可。直接从 RDK X5 的 5V 引脚取电可能导致板子电压降低甚至重启。

---

## 2. 舵机基础知识

### PWM 控制原理

舵机通过 PWM（脉宽调制）信号控制角度：

```
  PWM 周期 = 20ms (50Hz)
  ┌──┐                    ┌──┐
  │  │                    │  │
──┘  └────────────────────┘  └───

  ←──→
  脉宽（duty cycle）决定角度
```

| 脉宽 | 角度 |
|---|---|
| 0.5ms | 0° |
| 1.0ms | 45° |
| 1.5ms | 90°（中位） |
| 2.0ms | 135° |
| 2.5ms | 180° |

在 Linux sysfs 中，时间单位是**纳秒（ns）**：

| 参数 | 纳秒值 | 说明 |
|---|---|---|
| period | 20,000,000 ns | PWM 周期（50Hz） |
| duty_cycle (0°) | 500,000 ns | 0.5ms |
| duty_cycle (90°) | 1,500,000 ns | 1.5ms |
| duty_cycle (180°) | 2,500,000 ns | 2.5ms |

### 角度与 duty_cycle 的换算

```
duty_cycle(ns) = 500000 + (angle / 180) × 2000000
```

例如：
- 45° → 500000 + (45/180) × 2000000 = 1,000,000 ns
- 90° → 500000 + (90/180) × 2000000 = 1,500,000 ns

---

## 3. Linux PWM sysfs 接口

Linux 提供了通用的 sysfs 接口来控制 PWM，不需要写内核驱动。

### 目录结构

```
/sys/class/pwm/pwmchipN/
├── export          # 导出 PWM 通道
├── unexport        # 取消导出
└── pwmM/           # 导出后出现
    ├── period      # 周期（ns）
    ├── duty_cycle  # 占空比（ns）
    ├── enable      # 1=启用, 0=禁用
    └── polarity    # 极性
```

### 基本操作流程

```bash
# 1. 导出 PWM 通道（以 pwmchip0 的通道 0 为例）
echo 0 > /sys/class/pwm/pwmchip0/export

# 2. 设置周期为 20ms（50Hz）
echo 20000000 > /sys/class/pwm/pwmchip0/pwm0/period

# 3. 设置占空比（1.5ms = 90° 中位）
echo 1500000 > /sys/class/pwm/pwmchip0/pwm0/duty_cycle

# 4. 启用 PWM 输出
echo 1 > /sys/class/pwm/pwmchip0/pwm0/enable
```

就这么简单。一行 `echo` 命令就能让舵机转到指定角度。

---

## 4. RDK X5 的 PWM 引脚

RDK X5 的 40pin 接口提供了 PWM 输出：

| PWM 控制器 | 通道 | 40pin 引脚 | 用途（本教程） |
|---|---|---|---|
| pwmchip0/pwm0 | ch0 | Pin 32 (LSIO_PWM_OUT6) | Yaw（左右旋转） |
| pwmchip0/pwm1 | ch1 | Pin 33 (LSIO_PWM_OUT7) | Pitch（上下俯仰） |

查看系统中可用的 PWM 控制器：

```bash
ls /sys/class/pwm/
# pwmchip0  pwmchip2  ...
```

查看控制器信息：

```bash
cat /sys/class/pwm/pwmchip0/npwm   # 通道数
# 2
```

---

## 5. 基本控制代码

### 5.1 初始化 PWM

```bash
#!/bin/bash
PWM_PATH=/sys/class/pwm/pwmchip0
CENTER=1500000  # 90° 中位

# 导出两个通道
for ch in 0 1; do
    if [ ! -d ${PWM_PATH}/pwm${ch} ]; then
        echo $ch > ${PWM_PATH}/export 2>/dev/null
    fi
    echo 20000000 > ${PWM_PATH}/pwm${ch}/period
    echo $CENTER > ${PWM_PATH}/pwm${ch}/duty_cycle
    echo 1 > ${PWM_PATH}/pwm${ch}/enable
done

echo "PWM 初始化完成，舵机已回中位"
```

### 5.2 设置角度

```bash
# 设置舵机角度
# 用法：set_angle <pwm_path> <duty_ns>
set_servo() {
    echo "$2" > "$1/duty_cycle"
}

# 示例：Yaw 转到 45°（duty = 1000000ns）
set_servo /sys/class/pwm/pwmchip0/pwm0 1000000

# 示例：Pitch 抬头到 120°（duty = 1833333ns）
set_servo /sys/class/pwm/pwmchip0/pwm1 1833333
```

### 5.3 平滑移动（关键！）

**直接跳转到目标角度是危险的！** 原因：
1. 舵机瞬间启动，电流冲击大（可能导致板子重启）
2. 机械冲击大，容易损坏舵机齿轮或云台结构
3. 噪音大，体验差

**正确做法：分步渐进移动**

```bash
# 渐进移动：从 from 到 to，分 steps 步，每步间隔 delay 秒
move_to() {
    local pwm=$1
    local from=$2
    local to=$3
    local steps=$4
    local delay=$5
    
    for i in $(seq 1 $steps); do
        # 线性插值计算当前位置
        local pos=$(( from + (to - from) * i / steps ))
        echo "$pos" > "$pwm/duty_cycle"
        sleep $delay
    done
}

# 示例：Yaw 从中位平滑转到左边
# 每步 100000ns，sleep 0.08s，共 3 步
move_to /sys/class/pwm/pwmchip0/pwm0 1500000 1200000 3 0.08
```

> **经验值**：每步变化 100000ns（约 9°），间隔 0.08 秒，是一个比较安全和自然的速度。太快会电流冲击，太慢会显得呆板。

> **踩坑提醒**：RDK X5 系统默认没装 `bc` 计算器。Shell 脚本里不要用 `bc` 做浮点运算。用 `$(( ))` 做整数运算就够了，sleep 的小数直接写就行（如 `sleep 0.08`）。

---

## 6. 云台控制实战

### 6.1 Pan-Tilt 云台结构

```
       ┌─────────┐
       │  Camera  │  ← 摄像头/头部
       └────┬────┘
            │
       ┌────┴────┐
       │  Pitch  │  ← 上下俯仰（pwm1）
       │  Servo  │
       └────┬────┘
            │
       ┌────┴────┐
       │   Yaw   │  ← 左右旋转（pwm0）
       │  Servo  │
       └────┬────┘
            │
       ═════╧═════  ← 底座/桌面
```

**方向约定（本教程使用）：**
- duty_cycle 减小 → Yaw 向左 / Pitch 向下（低头）
- duty_cycle 增大 → Yaw 向右 / Pitch 向上（抬头）

> 不同舵机安装方向可能导致方向相反，请根据实际情况调整。

### 6.2 跳舞动作编程

跳舞的本质是把基本动作（摇头、点头、鞠躬）组合成节奏感强的序列。

**基本动作库：**

```bash
STEP=100000
CENTER=1500000

# 向左摇
shake_left() {
    move_to $PWM_YAW $CENTER $((CENTER - STEP*3)) 3 0.08
}

# 向右摇
shake_right() {
    move_to $PWM_YAW $((CENTER - STEP*3)) $((CENTER + STEP*3)) 6 0.08
}

# 点头
nod() {
    move_to $PWM_PITCH $CENTER $((CENTER - STEP*2)) 2 0.1
    move_to $PWM_PITCH $((CENTER - STEP*2)) $CENTER 2 0.1
}

# 鞠躬
bow() {
    move_to $PWM_PITCH $CENTER $((CENTER + STEP*2)) 3 0.08
    move_to $PWM_PITCH $((CENTER + STEP*2)) $((CENTER - STEP*2)) 4 0.08
    move_to $PWM_PITCH $((CENTER - STEP*2)) $CENTER 3 0.08
}
```

**组合成完整舞蹈：**

```bash
# 3 轮左右摇摆 + 点头
for round in 1 2 3; do
    shake_left
    nod
    shake_right
    nod
    # 回中
    move_to $PWM_YAW $((CENTER + STEP*3)) $CENTER 3 0.08
    sleep 0.2
done

# 最后鞠躬两下
bow
sleep 0.15
bow
```

### 6.3 巡视模式

让云台自动左右扫描，适合配合摄像头做监控：

```bash
# 巡视：左右往复扫描
LEFT_LIMIT=$((CENTER - STEP*4))    # 左极限
RIGHT_LIMIT=$((CENTER + STEP*4))   # 右极限
SCAN_STEPS=8
SCAN_DELAY=0.1

while true; do
    # 向右扫
    move_to $PWM_YAW $LEFT_LIMIT $RIGHT_LIMIT $SCAN_STEPS $SCAN_DELAY
    sleep 0.5
    # 向左扫
    move_to $PWM_YAW $RIGHT_LIMIT $LEFT_LIMIT $SCAN_STEPS $SCAN_DELAY
    sleep 0.5
done
```

---

## 7. Shell 脚本实现

完整的跳舞脚本：

```bash
#!/bin/bash
# RDK X5 舵机跳舞脚本
# 用法：bash dance.sh

PWM_YAW=/sys/class/pwm/pwmchip0/pwm0
PWM_PITCH=/sys/class/pwm/pwmchip0/pwm1

CENTER=1500000
STEP=100000

# ── 初始化 ──────────────────────────────
for ch in 0 1; do
    if [ ! -d /sys/class/pwm/pwmchip0/pwm${ch} ]; then
        echo $ch > /sys/class/pwm/pwmchip0/export 2>/dev/null
    fi
    echo 20000000 > /sys/class/pwm/pwmchip0/pwm${ch}/period 2>/dev/null
    echo $CENTER > /sys/class/pwm/pwmchip0/pwm${ch}/duty_cycle 2>/dev/null
    echo 1 > /sys/class/pwm/pwmchip0/pwm${ch}/enable 2>/dev/null
done

# ── 工具函数 ──────────────────────────────
set_servo() {
    echo "$2" > "$1/duty_cycle"
}

move_to() {
    local pwm=$1 from=$2 to=$3 steps=$4 delay=$5
    for i in $(seq 1 $steps); do
        local pos=$(( from + (to - from) * i / steps ))
        set_servo $pwm $pos
        sleep $delay
    done
}

# ── 回中 ──────────────────────────────
set_servo $PWM_YAW $CENTER
set_servo $PWM_PITCH $CENTER
sleep 0.5

# ── 跳舞 ──────────────────────────────
YAW_LEFT=$((CENTER - STEP * 3))
YAW_RIGHT=$((CENTER + STEP * 3))
PITCH_DOWN=$((CENTER - STEP * 2))
PITCH_UP=$((CENTER + STEP * 2))

for round in 1 2 3; do
    # 向左 + 点头
    move_to $PWM_YAW $CENTER $YAW_LEFT 3 0.08
    move_to $PWM_PITCH $CENTER $PITCH_DOWN 2 0.1
    move_to $PWM_PITCH $PITCH_DOWN $CENTER 2 0.1

    # 向右 + 点头
    move_to $PWM_YAW $YAW_LEFT $YAW_RIGHT 6 0.08
    move_to $PWM_PITCH $CENTER $PITCH_DOWN 2 0.1
    move_to $PWM_PITCH $PITCH_DOWN $CENTER 2 0.1

    # 回中
    move_to $PWM_YAW $YAW_RIGHT $CENTER 3 0.08
    sleep 0.2
done

# ── 鞠躬 ──────────────────────────────
for bow in 1 2; do
    move_to $PWM_PITCH $CENTER $PITCH_UP 3 0.08
    move_to $PWM_PITCH $PITCH_UP $PITCH_DOWN 4 0.08
    move_to $PWM_PITCH $PITCH_DOWN $CENTER 3 0.08
    sleep 0.15
done

# ── 回中 ──────────────────────────────
set_servo $PWM_YAW $CENTER
set_servo $PWM_PITCH $CENTER
echo "舞蹈完成!"
```

---

## 8. Python 实现

如果你需要更精细的控制或集成到其他 Python 项目中：

```python
#!/usr/bin/env python3
"""
RDK X5 Servo Controller
PWM-based pan-tilt control via Linux sysfs
"""
import time
import os

class Servo:
    """单个舵机控制"""
    
    def __init__(self, chip=0, channel=0):
        self.pwm_path = f"/sys/class/pwm/pwmchip{chip}/pwm{channel}"
        self.chip_path = f"/sys/class/pwm/pwmchip{chip}"
        self.channel = channel
        self._init_pwm()
    
    def _init_pwm(self):
        # 导出通道
        if not os.path.exists(self.pwm_path):
            with open(f"{self.chip_path}/export", "w") as f:
                f.write(str(self.channel))
        # 设置周期 20ms
        self._write("period", "20000000")
        # 设置中位
        self._write("duty_cycle", "1500000")
        # 启用
        self._write("enable", "1")
    
    def _write(self, attr, value):
        with open(f"{self.pwm_path}/{attr}", "w") as f:
            f.write(value)
    
    def set_duty(self, duty_ns):
        """设置占空比（纳秒）"""
        duty_ns = max(500000, min(2500000, int(duty_ns)))
        self._write("duty_cycle", str(duty_ns))
    
    def set_angle(self, angle):
        """设置角度（0-180°）"""
        duty = 500000 + int(angle / 180 * 2000000)
        self.set_duty(duty)
    
    def move_to(self, target_duty, steps=5, delay=0.08):
        """平滑移动到目标位置"""
        # 读取当前 duty
        with open(f"{self.pwm_path}/duty_cycle", "r") as f:
            current = int(f.read().strip())
        
        for i in range(1, steps + 1):
            pos = current + (target_duty - current) * i // steps
            self.set_duty(pos)
            time.sleep(delay)

class PanTilt:
    """Pan-Tilt 云台控制"""
    
    CENTER = 1500000
    STEP = 100000
    
    def __init__(self, yaw_chip=0, yaw_ch=0, pitch_chip=0, pitch_ch=1):
        self.yaw = Servo(yaw_chip, yaw_ch)
        self.pitch = Servo(pitch_chip, pitch_ch)
    
    def center(self):
        """回到中位"""
        self.yaw.set_duty(self.CENTER)
        self.pitch.set_duty(self.CENTER)
    
    def nod(self):
        """点头"""
        down = self.CENTER - self.STEP * 2
        self.pitch.move_to(down, steps=2, delay=0.1)
        self.pitch.move_to(self.CENTER, steps=2, delay=0.1)
    
    def shake(self):
        """摇头"""
        left = self.CENTER - self.STEP * 3
        right = self.CENTER + self.STEP * 3
        self.yaw.move_to(left, steps=3, delay=0.08)
        self.yaw.move_to(right, steps=6, delay=0.08)
        self.yaw.move_to(self.CENTER, steps=3, delay=0.08)
    
    def bow(self):
        """鞠躬"""
        up = self.CENTER + self.STEP * 2
        down = self.CENTER - self.STEP * 2
        self.pitch.move_to(up, steps=3, delay=0.08)
        self.pitch.move_to(down, steps=4, delay=0.08)
        self.pitch.move_to(self.CENTER, steps=3, delay=0.08)
    
    def dance(self):
        """跳舞！"""
        self.center()
        time.sleep(0.5)
        
        for _ in range(3):
            # 左右摇 + 点头
            left = self.CENTER - self.STEP * 3
            self.yaw.move_to(left, steps=3, delay=0.08)
            self.nod()
            
            right = self.CENTER + self.STEP * 3
            self.yaw.move_to(right, steps=6, delay=0.08)
            self.nod()
            
            self.yaw.move_to(self.CENTER, steps=3, delay=0.08)
            time.sleep(0.2)
        
        # 鞠躬
        self.bow()
        time.sleep(0.15)
        self.bow()
        
        self.center()
        print("舞蹈完成!")

if __name__ == "__main__":
    pt = PanTilt()
    pt.dance()
```

---

## 9. 安全注意事项

### 电流冲击

**这是最重要的安全问题。** 舵机在快速转动时电流很大（峰值可达 700mA-1A 每个）。

防护措施：
1. **渐进移动**：永远不要一步跳转到目标角度，分 3-5 步过渡
2. **外部供电**：两个舵机建议用独立 5V 电源
3. **限速**：每步变化不超过 200000ns，步间延迟不低于 50ms
4. **避免堵转**：不要驱动舵机超过机械极限

### 角度限制

```
安全范围：duty_cycle 500000 ~ 2500000 (0° ~ 180°)
建议范围：duty_cycle 700000 ~ 2300000 (18° ~ 162°)  // 留余量
```

### 掉电保护

PWM 输出停止后，舵机不再保持力矩。如果需要长时间保持位置，要持续输出 PWM 信号。

---

## 10. 常见问题

### Q: 舵机不动

**A**: 检查：
1. PWM 是否导出：`ls /sys/class/pwm/pwmchip0/pwm0/`
2. PWM 是否启用：`cat /sys/class/pwm/pwmchip0/pwm0/enable` → 应该是 1
3. 信号线是否接对引脚
4. 供电是否充足

### Q: 板子突然重启

**A**: 舵机电流冲击导致。解决方案：
- 使用渐进移动，不要一步到位
- 使用外部 5V 电源给舵机供电
- 减小运动幅度和速度

### Q: 运动不够平滑

**A**: 增加步数、减小每步变化量。例如从 3 步增加到 10 步，delay 相应减小。

### Q: 两个舵机同时动的时候卡顿

**A**: Shell 脚本中两个舵机是串行控制的。如果需要同时运动，可以用 Python 的多线程，或者在一个循环里交替写两个舵机的 duty_cycle。

### Q: Shell 里用 bc 报错

**A**: RDK X5 默认没装 `bc`。用 `$(( ))` 做整数运算：

```bash
# 错误（需要 bc）
pos=$(echo "1500000 + 100000 * 3" | bc)

# 正确（纯 bash）
pos=$(( 1500000 + 100000 * 3 ))
```

---

*本教程基于 RDK X5 实际开发经验编写，所有代码经过实测验证。*

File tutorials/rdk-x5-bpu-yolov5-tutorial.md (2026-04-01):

# RDK X5 BPU 目标检测实战：YOLOv5 从图片到实时检测

> 完整实战教程 | BPU 硬件加速 + YOLOv5 推理 + 后处理 + 可视化
> 
> 作者：张晓烨 | D-Robotics 开发者生态
> 
> 硬件平台：地瓜机器人 RDK X5

---

## 你将获得什么

在 RDK X5 上使用 BPU（Brain Processing Unit）硬件加速运行 YOLOv5 目标检测：
- 理解 RDK X5 的 BPU 加速推理架构
- 使用 `hobot_dnn` Python 接口加载和运行模型
- 掌握 NV12 图像预处理流程
- 实现 YOLOv5 后处理（NMS + 画框）
- 从单张图片检测到 MIPI 摄像头实时检测

**为什么用 BPU？**

RDK X5 内置 BPU 加速器，专为深度学习推理优化。相比纯 CPU 推理，BPU 可以提供 10-50 倍的加速，同时功耗更低。系统预装了 30+ 个已转换好的模型（`.bin` 格式），包括 YOLOv5、YOLOv8、FCOS、SSD 等。

---

## 目录

1. [BPU 推理架构概览](#1-bpu-推理架构概览)
2. [环境确认](#2-环境确认)
3. [模型与示例文件](#3-模型与示例文件)
4. [快速体验：图片分类](#4-快速体验图片分类)
5. [YOLOv5 目标检测详解](#5-yolov5-目标检测详解)
   - 5.1 加载模型
   - 5.2 图像预处理（BGR → NV12）
   - 5.3 BPU 推理
   - 5.4 后处理与 NMS
   - 5.5 结果可视化
6. [完整代码：单张图片检测](#6-完整代码单张图片检测)
7. [进阶：MIPI 摄像头实时检测](#7-进阶mipi-摄像头实时检测)
8. [性能优化技巧](#8-性能优化技巧)
9. [常见问题](#9-常见问题)

---

## 1. BPU 推理架构概览

```
                RDK X5 推理流程
┌─────────┐    ┌──────────┐    ┌─────────┐    ┌──────────┐
│  输入图像 │ →  │ 预处理    │ →  │ BPU 推理 │ →  │ 后处理    │
│ (BGR/NV12)│    │ resize   │    │ .bin模型 │    │ NMS+画框  │
│          │    │ BGR→NV12 │    │ 硬件加速  │    │ 输出结果  │
└─────────┘    └──────────┘    └─────────┘    └──────────┘
```

**关键概念：**
- **`.bin` 模型**：地瓜机器人的 BPU 专用格式，由原始模型（ONNX/Caffe 等）通过工具链转换而来
- **NV12 输入**：BPU 的模型通常期望 NV12 格式输入（与摄像头输出格式一致，零拷贝）
- **`hobot_dnn`**：Python 推理接口，封装了模型加载、推理、tensor 管理
- **`libpostprocess.so`**：系统预装的 C 后处理库，提供各种模型的 NMS 实现

---

## 2. 环境确认

```bash
# 确认 hobot_dnn 可用
python3 -c "from hobot_dnn import pyeasy_dnn; print('OK')"

# 如果上面报错，试试这个
python3 -c "from hobot_dnn_rdkx5 import pyeasy_dnn; print('OK')"

# 确认后处理库
ls /usr/lib/libpostprocess.so

# 确认预装模型
ls /opt/hobot/model/x5/basic/
```

你应该能看到大量 `.bin` 模型文件：

```
yolov5s_672x672_nv12.bin
yolov8_640x640_nv12.bin
mobilenetv1_224x224_nv12.bin
googlenet_224x224_nv12.bin
...
```

---

## 3. 模型与示例文件

系统预装了完整的示例代码和模型：

```
/app/pydev_demo/
├── 01_basic_sample/          # 图像分类（MobileNet、GoogleNet 等）
├── 02_usb_camera_sample/     # USB 摄像头 + 检测
├── 03_mipi_camera_sample/    # MIPI 摄像头
├── 04_segment_sample/        # 语义分割
├── 05_web_display_camera_sample/  # Web 实时显示
├── 06_yolov3_sample/         # YOLOv3 检测
├── 07_yolov5_sample/         # YOLOv5 检测
├── 09_yolov5x_sample/        # YOLOv5x 大模型
├── 10_ssd_mobilenetv1_sample/ # SSD 检测
├── 11_centernet_sample/      # CenterNet 检测
├── 12_yolov5s_v6_v7_sample/  # YOLOv5 v6/v7
└── models/                   # 软链接到 /opt/hobot/model/x5/basic/
```

---

## 4. 快速体验：图片分类

先跑一个最简单的分类模型，理解基本流程：

```python
#!/usr/bin/env python3
"""RDK X5 BPU 图像分类快速体验"""
import numpy as np
import cv2

try:
    from hobot_dnn import pyeasy_dnn as dnn
except ImportError:
    from hobot_dnn_rdkx5 import pyeasy_dnn as dnn

def bgr2nv12(image):
    """BGR 图像转 NV12 格式（BPU 模型所需的输入格式）"""
    height, width = image.shape[0], image.shape[1]
    area = height * width
    yuv420p = cv2.cvtColor(image, cv2.COLOR_BGR2YUV_I420).reshape((area * 3 // 2,))
    y = yuv420p[:area]
    uv_planar = yuv420p[area:].reshape((2, area // 4))
    uv_packed = uv_planar.transpose((1, 0)).reshape((area // 2,))
    nv12 = np.zeros_like(yuv420p)
    nv12[:area] = y
    nv12[area:] = uv_packed
    return nv12

# 1. 加载模型
models = dnn.load('/opt/hobot/model/x5/basic/mobilenetv1_224x224_nv12.bin')
model = models[0]

# 2. 查看模型信息
print(f"输入 shape: {model.inputs[0].properties.shape}")
print(f"输入 layout: {model.inputs[0].properties.layout}")
print(f"输出 shape: {model.outputs[0].properties.shape}")

# 3. 预处理
img = cv2.imread("test.jpg")
h, w = 224, 224  # 模型期望的输入尺寸
resized = cv2.resize(img, (w, h))
nv12 = bgr2nv12(resized)

# 4. 推理
outputs = model.forward(nv12)

# 5. 获取结果
# 分类模型输出是 1000 类的概率向量
probs = outputs[0].buffer.flatten()
top5_idx = np.argsort(probs)[-5:][::-1]

print("\nTop 5 预测结果：")
for idx in top5_idx:
    print(f"  类别 {idx}: 概率 {probs[idx]:.4f}")
```

---

## 5. YOLOv5 目标检测详解

### 5.1 加载模型

```python
try:
    from hobot_dnn import pyeasy_dnn as dnn
except ImportError:
    from hobot_dnn_rdkx5 import pyeasy_dnn as dnn

# 加载 YOLOv5s 模型
models = dnn.load('/opt/hobot/model/x5/basic/yolov5s_672x672_nv12.bin')
model = models[0]

# 查看输入输出信息
print(f"输入: {model.inputs[0].properties.shape}")   # [1, 672, 672, 3]
print(f"输出数量: {len(model.outputs)}")              # 3 个输出头

for i, out in enumerate(model.outputs):
    print(f"输出[{i}]: {out.properties.shape}")
```

`dnn.load()` 返回一个模型列表（一个 `.bin` 文件可能包含多个模型），通常取 `[0]`。

### 5.2 图像预处理（BGR → NV12）

BPU 模型的输入格式是 NV12，不是常见的 BGR/RGB。需要手动转换：

```python
def bgr2nv12(image):
    """将 BGR 图像转换为 NV12 格式"""
    height, width = image.shape[0], image.shape[1]
    area = height * width
    
    # BGR → YUV I420
    yuv420p = cv2.cvtColor(image, cv2.COLOR_BGR2YUV_I420).reshape((area * 3 // 2,))
    
    # 分离 Y 和 UV 平面
    y = yuv420p[:area]
    uv_planar = yuv420p[area:].reshape((2, area // 4))
    
    # UV planar → UV interleaved（I420 → NV12 的关键步骤）
    uv_packed = uv_planar.transpose((1, 0)).reshape((area // 2,))
    
    # 拼接
    nv12 = np.zeros_like(yuv420p)
    nv12[:area] = y
    nv12[area:] = uv_packed
    return nv12
```

**I420 vs NV12 的区别：**
- I420：Y 平面 + U 平面 + V 平面（三个独立平面）
- NV12：Y 平面 + UV 交织平面（UV 配对存储）

OpenCV 只能转到 I420，所以需要手动将 U、V 交织打包成 NV12。

**完整预处理流程：**

```python
# 读取原始图像
img = cv2.imread("test.jpg")

# resize 到模型尺寸
h, w = 672, 672  # YOLOv5s 的输入尺寸
resized = cv2.resize(img, (w, h), interpolation=cv2.INTER_AREA)

# BGR → NV12
nv12_data = bgr2nv12(resized)
```

### 5.3 BPU 推理

```python
import time

t0 = time.time()
outputs = model.forward(nv12_data)
t1 = time.time()
print(f"推理耗时: {(t1-t0)*1000:.1f} ms")
```

`forward()` 将 NV12 数据送入 BPU 执行推理，返回输出 tensor 列表。

### 5.4 后处理与 NMS

YOLOv5 的后处理比较复杂，系统预装了 C 实现的后处理库 `libpostprocess.so`，通过 `ctypes` 调用：

```python
import ctypes
import json

# 加载后处理库
libpostprocess = ctypes.CDLL('/usr/lib/libpostprocess.so')

# 配置后处理参数
class Yolov5PostProcessInfo_t(ctypes.Structure):
    _fields_ = [
        ("height", ctypes.c_int),          # 模型输入高
        ("width", ctypes.c_int),           # 模型输入宽
        ("ori_height", ctypes.c_int),      # 原始图像高
        ("ori_width", ctypes.c_int),       # 原始图像宽
        ("score_threshold", ctypes.c_float), # 置信度阈值
        ("nms_threshold", ctypes.c_float),   # NMS IoU 阈值
        ("nms_top_k", ctypes.c_int),         # 最大检测数
        ("is_pad_resize", ctypes.c_int)      # 是否 padding resize
    ]

info = Yolov5PostProcessInfo_t()
info.height = 672
info.width = 672
info.ori_height = img.shape[0]  # 原始图像尺寸
info.ori_width = img.shape[1]
info.score_threshold = 0.4
info.nms_threshold = 0.45
info.nms_top_k = 20
info.is_pad_resize = 0
```

**调用后处理获取结果：**

```python
# 将推理输出转为 C 结构体（细节见完整代码）
# ... 设置 output_tensors ...

# 获取 JSON 格式的检测结果
get_result = libpostprocess.Yolov5PostProcess
get_result.argtypes = [ctypes.POINTER(Yolov5PostProcessInfo_t)]
get_result.restype = ctypes.c_char_p

result_str = get_result(ctypes.pointer(info))
result_str = result_str.decode('utf-8')

# 解析结果
data = json.loads(result_str[16:])  # 跳过前缀
for det in data:
    bbox = det['bbox']    # [x1, y1, x2, y2]
    score = det['score']  # 置信度
    name = det['name']    # 类别名称
    print(f"{name}: {score:.2f} at {bbox}")
```

### 5.5 结果可视化

```python
for det in data:
    bbox = det['bbox']
    score = det['score']
    name = det['name']
    
    # 画检测框
    cv2.rectangle(img,
        (int(bbox[0]), int(bbox[1])),
        (int(bbox[2]), int(bbox[3])),
        (0, 255, 0), 2)
    
    # 标注类别和置信度
    label = f'{name} {score:.2f}'
    cv2.putText(img, label,
        (int(bbox[0]), int(bbox[1]) - 10),
        cv2.FONT_HERSHEY_SIMPLEX, 0.5, (0, 255, 0), 1)

cv2.imwrite('result.jpg', img)
```

---

## 6. 完整代码：单张图片检测

```python
#!/usr/bin/env python3
"""
RDK X5 YOLOv5 目标检测
使用 BPU 硬件加速推理
"""
import numpy as np
import cv2
import ctypes
import json
import time

try:
    from hobot_dnn import pyeasy_dnn as dnn
except ImportError:
    from hobot_dnn_rdkx5 import pyeasy_dnn as dnn

# ── ctypes 结构体定义 ──────────────────────────

class hbSysMem_t(ctypes.Structure):
    _fields_ = [
        ("phyAddr", ctypes.c_double),
        ("virAddr", ctypes.c_void_p),
        ("memSize", ctypes.c_int)
    ]

class hbDNNQuantiScale_t(ctypes.Structure):
    _fields_ = [
        ("scaleLen", ctypes.c_int),
        ("scaleData", ctypes.POINTER(ctypes.c_float)),
        ("zeroPointLen", ctypes.c_int),
        ("zeroPointData", ctypes.c_char_p)
    ]

class hbDNNQuantiShift_t(ctypes.Structure):
    _fields_ = [
        ("shiftLen", ctypes.c_int),
        ("shiftData", ctypes.c_char_p)
    ]

class hbDNNTensorShape_t(ctypes.Structure):
    _fields_ = [
        ("dimensionSize", ctypes.c_int * 8),
        ("numDimensions", ctypes.c_int)
    ]

class hbDNNTensorProperties_t(ctypes.Structure):
    _fields_ = [
        ("validShape", hbDNNTensorShape_t),
        ("alignedShape", hbDNNTensorShape_t),
        ("tensorLayout", ctypes.c_int),
        ("tensorType", ctypes.c_int),
        ("shift", hbDNNQuantiShift_t),
        ("scale", hbDNNQuantiScale_t),
        ("quantiType", ctypes.c_int),
        ("quantizeAxis", ctypes.c_int),
        ("alignedByteSize", ctypes.c_int),
        ("stride", ctypes.c_int * 8)
    ]

class hbDNNTensor_t(ctypes.Structure):
    _fields_ = [
        ("sysMem", hbSysMem_t * 4),
        ("properties", hbDNNTensorProperties_t)
    ]

class Yolov5PostProcessInfo_t(ctypes.Structure):
    _fields_ = [
        ("height", ctypes.c_int),
        ("width", ctypes.c_int),
        ("ori_height", ctypes.c_int),
        ("ori_width", ctypes.c_int),
        ("score_threshold", ctypes.c_float),
        ("nms_threshold", ctypes.c_float),
        ("nms_top_k", ctypes.c_int),
        ("is_pad_resize", ctypes.c_int)
    ]

# ── 工具函数 ──────────────────────────

def bgr2nv12(image):
    height, width = image.shape[0], image.shape[1]
    area = height * width
    yuv420p = cv2.cvtColor(image, cv2.COLOR_BGR2YUV_I420).reshape((area * 3 // 2,))
    y = yuv420p[:area]
    uv_planar = yuv420p[area:].reshape((2, area // 4))
    uv_packed = uv_planar.transpose((1, 0)).reshape((area // 2,))
    nv12 = np.zeros_like(yuv420p)
    nv12[:area] = y
    nv12[area:] = uv_packed
    return nv12

def get_hw(properties):
    if properties.layout == "NCHW":
        return properties.shape[2], properties.shape[3]
    return properties.shape[1], properties.shape[2]

def get_layout_int(layout_str):
    return 2 if layout_str == "NCHW" else 0

# ── 主程序 ──────────────────────────

def detect(image_path, model_path, score_thresh=0.4, nms_thresh=0.45):
    # 加载模型
    models = dnn.load(model_path)
    model = models[0]
    
    h, w = get_hw(model.inputs[0].properties)
    print(f"模型输入尺寸: {w}x{h}")
    
    # 读取和预处理图像
    img = cv2.imread(image_path)
    if img is None:
        print(f"无法读取图像: {image_path}")
        return
    
    org_h, org_w = img.shape[:2]
    resized = cv2.resize(img, (w, h), interpolation=cv2.INTER_AREA)
    nv12_data = bgr2nv12(resized)
    
    # BPU 推理
    t0 = time.time()
    outputs = model.forward(nv12_data)
    t1 = time.time()
    print(f"BPU 推理耗时: {(t1-t0)*1000:.1f} ms")
    
    # 后处理
    libpostprocess = ctypes.CDLL('/usr/lib/libpostprocess.so')
    
    info = Yolov5PostProcessInfo_t()
    info.height = h
    info.width = w
    info.ori_height = org_h
    info.ori_width = org_w
    info.score_threshold = score_thresh
    info.nms_threshold = nms_thresh
    info.nms_top_k = 20
    info.is_pad_resize = 0
    
    output_tensors = (hbDNNTensor_t * len(outputs))()
    for i in range(len(outputs)):
        output_tensors[i].properties.tensorLayout = get_layout_int(
            outputs[i].properties.layout
        )
        
        if len(outputs[i].properties.scale_data) == 0:
            output_tensors[i].properties.quantiType = 0
            output_tensors[i].sysMem[0].virAddr = ctypes.cast(
                outputs[i].buffer.ctypes.data_as(ctypes.POINTER(ctypes.c_float)),
                ctypes.c_void_p
            )
        else:
            output_tensors[i].properties.quantiType = 2
            output_tensors[i].properties.scale.scaleData = (
                outputs[i].properties.scale_data.ctypes.data_as(
                    ctypes.POINTER(ctypes.c_float)
                )
            )
            output_tensors[i].sysMem[0].virAddr = ctypes.cast(
                outputs[i].buffer.ctypes.data_as(ctypes.POINTER(ctypes.c_int32)),
                ctypes.c_void_p
            )
        
        for j in range(len(outputs[i].properties.shape)):
            output_tensors[i].properties.validShape.dimensionSize[j] = (
                outputs[i].properties.shape[j]
            )
        
        libpostprocess.Yolov5doProcess(output_tensors[i], ctypes.pointer(info), i)
    
    get_result = libpostprocess.Yolov5PostProcess
    get_result.argtypes = [ctypes.POINTER(Yolov5PostProcessInfo_t)]
    get_result.restype = ctypes.c_char_p
    
    result_str = get_result(ctypes.pointer(info))
    result_str = result_str.decode('utf-8')
    
    t2 = time.time()
    print(f"后处理耗时: {(t2-t1)*1000:.1f} ms")
    
    # 解析并可视化
    data = json.loads(result_str[16:])
    print(f"\n检测到 {len(data)} 个目标：")
    
    for det in data:
        bbox = det['bbox']
        score = det['score']
        name = det['name']
        print(f"  {name}: {score:.2f} at [{bbox[0]:.0f}, {bbox[1]:.0f}, {bbox[2]:.0f}, {bbox[3]:.0f}]")
        
        cv2.rectangle(img,
            (int(bbox[0]), int(bbox[1])),
            (int(bbox[2]), int(bbox[3])),
            (0, 255, 0), 2)
        cv2.putText(img, f'{name} {score:.2f}',
            (int(bbox[0]), int(bbox[1]) - 10),
            cv2.FONT_HERSHEY_SIMPLEX, 0.5, (0, 255, 0), 1)
    
    output_path = image_path.rsplit('.', 1)[0] + '_result.jpg'
    cv2.imwrite(output_path, img)
    print(f"\n结果保存到: {output_path}")

if __name__ == '__main__':
    import sys
    image = sys.argv[1] if len(sys.argv) > 1 else '/app/pydev_demo/07_yolov5_sample/kite.jpg'
    model = '/opt/hobot/model/x5/basic/yolov5s_672x672_nv12.bin'
    detect(image, model)
```

---

## 7. 进阶：MIPI 摄像头实时检测

将摄像头采集与 BPU 推理结合，实现实时目标检测：

```python
#!/usr/bin/env python3
"""MIPI 摄像头 + BPU 实时目标检测"""
import numpy as np
import cv2
import time

try:
    from hobot_dnn import pyeasy_dnn as dnn
except ImportError:
    from hobot_dnn_rdkx5 import pyeasy_dnn as dnn

try:
    from hobot_vio import libsrcampy as srcampy
except ImportError:
    from hobot_vio_rdkx5 import libsrcampy as srcampy

# 加载模型（使用 640x640 的 YOLOv8 更新更快）
models = dnn.load('/opt/hobot/model/x5/basic/yolov8_640x640_nv12.bin')
model = models[0]

# 打开摄像头（输出 640x640 分辨率匹配模型）
cam = srcampy.Camera()
cam.open_cam(0, -1, -1, [640], [640], 640, 640)

print("实时检测中... Ctrl+C 退出")
frame_count = 0
start = time.time()

try:
    while True:
        # 采集 NV12 图像（已经是 640x640，无需 resize！）
        nv12 = cam.get_img(2, 640, 640)
        if nv12 is None:
            continue
        
        # 直接送入 BPU（零预处理！）
        outputs = model.forward(nv12)
        
        frame_count += 1
        if frame_count % 30 == 0:
            fps = frame_count / (time.time() - start)
            print(f"FPS: {fps:.1f}")
        
        # 后处理...（同上）
        
finally:
    cam.close_cam()
```

> **零拷贝优化**：当摄像头输出分辨率与模型输入尺寸一致时，NV12 数据可以直接送入 BPU，跳过 resize 和格式转换，大幅提升帧率。

---

## 8. 性能优化技巧

### 8.1 匹配摄像头分辨率和模型输入

```python
# 让摄像头直接输出模型期望的尺寸
# 模型是 640x640 → 摄像头也设置 640x640
cam.open_cam(0, -1, -1, [640], [640], 640, 640)
```

### 8.2 选择合适的模型

系统预装模型的速度和精度对比（参考值）：

| 模型 | 输入尺寸 | BPU 推理时间 | 适用场景 |
|---|---|---|---|
| YOLOv5s | 672x672 | ~15ms | 精度优先 |
| YOLOv8 | 640x640 | ~12ms | 均衡 |
| SSD MobileNetV1 | 300x300 | ~5ms | 速度优先 |
| FCOS | 512x512 | ~10ms | 均衡 |

### 8.3 降低后处理开销

- 提高 `score_threshold`（如 0.5→0.6）减少候选框
- 降低 `nms_top_k`（如 20→10）减少 NMS 计算量
- 使用 C 后处理库而不是纯 Python 实现

---

## 9. 常见问题

### Q: `dnn.load()` 报错

**A**: 确认模型文件路径正确，且是 `.bin` 格式。`.onnx` 或 `.pt` 不能直接加载，需要通过地瓜工具链转换。

### Q: 推理结果全是空的

**A**: 检查预处理是否正确。最常见的问题是 BGR→NV12 转换错误或 resize 尺寸不匹配模型输入。

### Q: 检测框位置偏移

**A**: 确认 `ori_height` 和 `ori_width` 设置为原始图像尺寸，`is_pad_resize` 与你的 resize 方式一致（0=直接 resize，1=保持比例 padding）。

### Q: 如何使用自己的模型？

**A**: 需要使用地瓜机器人的 OE（Open Explorer）工具链将 ONNX/Caffe 模型转换为 `.bin` 格式。具体步骤参考地瓜官方文档的"模型转换"章节。

### Q: `libpostprocess.so` 找不到

**A**: 这个库来自 `hobot-spdev` 包。确认已安装：
```bash
dpkg -l | grep hobot-spdev
```

---

*本教程基于 RDK X5 实际开发经验编写，使用系统预装的模型和示例验证。*

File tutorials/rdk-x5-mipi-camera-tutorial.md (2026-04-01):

# RDK X5 MIPI 摄像头实战：从拍照到图像处理

> 完整实战教程 | MIPI 摄像头驱动 + NV12 图像处理 + OpenCV 集成
> 
> 作者：张晓烨 | D-Robotics 开发者生态
> 
> 硬件平台：地瓜机器人 RDK X5

---

## 你将获得什么

掌握 RDK X5 上 MIPI 摄像头的完整使用方法：
- 理解 RDK X5 摄像头与普通 USB 摄像头（V4L2）的区别
- 使用 `hobot_vio` 的 `libsrcampy` 接口采集图像
- NV12 色彩空间转换为 BGR/RGB
- 结合 OpenCV 进行图像处理和保存
- 构建一个可复用的拍照脚本

**为什么需要这篇教程？**

RDK X5 的 MIPI 摄像头**不走 V4L2 通道**，你用 `cv2.VideoCapture(0)` 是打不开的。必须通过地瓜机器人的 VIN/ISP 专用 API 来访问。这个坑很多初学者都会踩到。

---

## 目录

1. [硬件连接](#1-硬件连接)
2. [摄像头驱动架构](#2-摄像头驱动架构)
3. [安装依赖](#3-安装依赖)
4. [快速拍照](#4-快速拍照)
5. [代码详解](#5-代码详解)
   - 5.1 Camera 对象初始化
   - 5.2 NV12 格式解析
   - 5.3 NV12 → BGR 转换
   - 5.4 图像保存与处理
6. [完整拍照脚本](#6-完整拍照脚本)
7. [进阶应用](#7-进阶应用)
   - 7.1 连续采集（视频流）
   - 7.2 结合 AI 推理
   - 7.3 定时拍照监控
8. [常见问题](#8-常见问题)

---

## 1. 硬件连接

RDK X5 支持 MIPI CSI 接口的摄像头模组。

| 接口 | 说明 |
|---|---|
| MIPI CSI | 板载 FPC 连接器，支持 2-lane / 4-lane |
| 支持传感器 | IMX219、OV5647、IMX477 等常见 MIPI 传感器 |

**连接步骤：**
1. 断电状态下，将摄像头排线插入 MIPI CSI 接口
2. 注意排线方向（金属触点朝向板子）
3. 上电后系统会自动检测摄像头

确认摄像头是否被识别：

```bash
ls /dev/vin*
# 应该看到 /dev/vin0_cap 等设备
```

---

## 2. 摄像头驱动架构

RDK X5 的摄像头系统与常见的 Linux V4L2 框架不同：

```
普通 Linux:   摄像头 → V4L2 驱动 → /dev/video0 → OpenCV
RDK X5:       MIPI 摄像头 → VIN/ISP 硬件 → libsrcampy → 用户程序
```

地瓜机器人的 VIN（Video Input）模块直接对接 MIPI 传感器，经过 ISP（Image Signal Processor）处理后，输出 NV12 格式的图像数据。

**关键点：**
- 不能用 `cv2.VideoCapture()` 或 `v4l2` 工具
- 必须使用 `hobot_vio` 提供的 `libsrcampy` Python 接口
- 输出格式为 NV12（YUV420SP），不是 BGR/RGB

---

## 3. 安装依赖

`hobot_vio` 通常在 RDK X5 的系统镜像中已经预装。

```bash
# 确认 hobot_vio 是否可用
python3 -c "from hobot_vio import libsrcampy; print('OK')"
```

如果提示找不到，尝试：

```bash
python3 -c "from hobot_vio_rdkx5 import libsrcampy; print('OK')"
```

> **注意**：不同系统版本的包名可能不同（`hobot_vio` 或 `hobot_vio_rdkx5`）。建议写一个兼容导入：

```python
try:
    from hobot_vio import libsrcampy as srcampy
except ImportError:
    from hobot_vio_rdkx5 import libsrcampy as srcampy
```

还需要 OpenCV 和 NumPy：

```bash
pip3 install opencv-python-headless numpy
```

---

## 4. 快速拍照

先来一个最简单的拍照脚本，确认摄像头能工作：

```python
#!/usr/bin/env python3
import numpy as np
import cv2

try:
    from hobot_vio import libsrcampy as srcampy
except ImportError:
    from hobot_vio_rdkx5 import libsrcampy as srcampy

# 打开摄像头
cam = srcampy.Camera()
cam.open_cam(0, -1, -1, [1920], [1080], 1080, 1920)

# 采集一帧 NV12 数据
nv12 = cam.get_img(2, 1920, 1080)
cam.close_cam()

if nv12 is None:
    print("拍照失败！")
    exit(1)

# NV12 → BGR
nv12_array = np.frombuffer(nv12, dtype=np.uint8).reshape(1620, 1920)
bgr = cv2.cvtColor(nv12_array, cv2.COLOR_YUV2BGR_NV12)

# 保存
cv2.imwrite("photo.jpg", bgr)
print("拍照成功：photo.jpg")
```

运行：

```bash
python3 quick_snap.py
```

---

## 5. 代码详解

### 5.1 Camera 对象初始化

```python
cam = srcampy.Camera()
cam.open_cam(
    0,          # 摄像头 ID（通常为 0）
    -1,         # 传感器类型（-1 = 自动检测）
    -1,         # 帧率（-1 = 默认）
    [1920],     # 输出宽度列表
    [1080],     # 输出高度列表
    1080,       # ISP 输出高度
    1920        # ISP 输出宽度
)
```

**参数说明：**
- 第一个参数是摄像头编号，单摄像头一般为 0
- 宽高参数以列表形式传入，支持多路输出（不同分辨率）
- ISP 输出尺寸决定了硬件处理的分辨率

### 5.2 NV12 格式解析

`get_img()` 返回的是 NV12 格式的原始字节数据。

**什么是 NV12？**

NV12 是一种 YUV420 Semi-Planar 格式：
- Y 平面：亮度信息，每个像素一个 Y 值
- UV 平面：色度信息，每 2x2 个像素共享一组 UV 值

对于 1920x1080 的图像：
- Y 平面大小：1920 × 1080 = 2,073,600 字节
- UV 平面大小：1920 × 540 = 1,036,800 字节
- 总大小：3,110,400 字节

```python
# NV12 数据的 reshape 维度
# 高度 = 原始高度 × 1.5（因为 UV 平面是 Y 平面的一半）
# 1080 × 1.5 = 1620
nv12_array = np.frombuffer(nv12, dtype=np.uint8).reshape(1620, 1920)
```

> **重要**：reshape 的高度是 `原始高度 × 1.5`，不是 `原始高度`。这是 NV12 格式的特点 — Y 平面和 UV 平面是连续存储的。

### 5.3 NV12 → BGR 转换

OpenCV 提供了直接的色彩空间转换：

```python
bgr = cv2.cvtColor(nv12_array, cv2.COLOR_YUV2BGR_NV12)
```

转换后的 `bgr` 是标准的 OpenCV BGR 格式图像（shape: 1080 × 1920 × 3），可以直接用于后续处理。

如果需要 RGB 格式（例如给深度学习模型）：

```python
rgb = cv2.cvtColor(nv12_array, cv2.COLOR_YUV2RGB_NV12)
```

### 5.4 图像保存与处理

```python
# 保存为 JPEG
cv2.imwrite("output.jpg", bgr)

# 保存为 PNG（无损）
cv2.imwrite("output.png", bgr)

# 调整大小
resized = cv2.resize(bgr, (640, 360))

# 转为灰度图
gray = cv2.cvtColor(bgr, cv2.COLOR_BGR2GRAY)

# 画框（例如目标检测后）
cv2.rectangle(bgr, (100, 100), (300, 300), (0, 255, 0), 2)
cv2.imwrite("annotated.jpg", bgr)
```

---

## 6. 完整拍照脚本

一个带错误处理和参数支持的完整版本：

```python
#!/usr/bin/env python3
"""
RDK X5 MIPI Camera Snapshot
Usage: python3 snap.py [output_path]
Default output: ./snapshot.jpg
"""
import sys
import os
import numpy as np
import cv2

try:
    from hobot_vio import libsrcampy as srcampy
except ImportError:
    from hobot_vio_rdkx5 import libsrcampy as srcampy

# 配置
WIDTH = 1920
HEIGHT = 1080
NV12_HEIGHT = int(HEIGHT * 1.5)  # 1620

def capture(output_path="snapshot.jpg"):
    """采集一帧并保存为 JPEG"""
    cam = srcampy.Camera()
    
    try:
        # 打开摄像头
        cam.open_cam(0, -1, -1, [WIDTH], [HEIGHT], HEIGHT, WIDTH)
        
        # 采集 NV12 数据
        nv12 = cam.get_img(2, WIDTH, HEIGHT)
        if nv12 is None:
            print("ERROR: 图像采集失败")
            return False
        
        # NV12 → BGR
        nv12_array = np.frombuffer(nv12, dtype=np.uint8).reshape(NV12_HEIGHT, WIDTH)
        bgr = cv2.cvtColor(nv12_array, cv2.COLOR_YUV2BGR_NV12)
        
        # 确保输出目录存在
        output_dir = os.path.dirname(output_path)
        if output_dir:
            os.makedirs(output_dir, exist_ok=True)
        
        # 保存
        cv2.imwrite(output_path, bgr)
        print(f"OK: {output_path}")
        return True
        
    except Exception as e:
        print(f"ERROR: {e}")
        return False
        
    finally:
        cam.close_cam()

if __name__ == "__main__":
    output = sys.argv[1] if len(sys.argv) > 1 else "snapshot.jpg"
    success = capture(output)
    sys.exit(0 if success else 1)
```

---

## 7. 进阶应用

### 7.1 连续采集（视频流）

```python
import time

cam = srcampy.Camera()
cam.open_cam(0, -1, -1, [1920], [1080], 1080, 1920)

try:
    frame_count = 0
    start_time = time.time()
    
    while True:
        nv12 = cam.get_img(2, 1920, 1080)
        if nv12 is None:
            continue
        
        frame_count += 1
        
        # 每秒打印帧率
        elapsed = time.time() - start_time
        if elapsed >= 1.0:
            fps = frame_count / elapsed
            print(f"FPS: {fps:.1f}")
            frame_count = 0
            start_time = time.time()
        
        # 在这里处理每一帧...
        nv12_array = np.frombuffer(nv12, dtype=np.uint8).reshape(1620, 1920)
        bgr = cv2.cvtColor(nv12_array, cv2.COLOR_YUV2BGR_NV12)
        
        # 例如：检测、推理、标注...
        
finally:
    cam.close_cam()
```

### 7.2 结合 AI 推理

RDK X5 内置 BPU（Brain Processing Unit）加速器，可以高效运行 AI 模型。结合摄像头可以实现：

- 目标检测（YOLO 系列）
- 人脸识别
- 姿态估计
- 场景分类

```python
# 伪代码示例
nv12 = cam.get_img(2, 1920, 1080)
bgr = nv12_to_bgr(nv12)

# 前处理
input_tensor = preprocess(bgr, target_size=(640, 640))

# BPU 推理
results = bpu_model.forward(input_tensor)

# 后处理 + 画框
for det in results:
    cv2.rectangle(bgr, det.bbox, (0, 255, 0), 2)
```

### 7.3 定时拍照监控

结合 cron 或简单的 while 循环实现定时拍照：

```bash
# 每 5 分钟拍一张照片
*/5 * * * * python3 /path/to/snap.py /path/to/photos/$(date +\%Y\%m\%d_\%H\%M\%S).jpg
```

---

## 8. 常见问题

### Q: `cv2.VideoCapture(0)` 打不开摄像头

**A**: RDK X5 的 MIPI 摄像头不走 V4L2，必须用 `libsrcampy`。这是最常见的误区。

### Q: `get_img()` 返回 None

**A**: 可能原因：
- 摄像头排线没插好
- `open_cam` 的分辨率参数不被传感器支持
- 另一个进程正在占用摄像头

检查摄像头设备：`ls /dev/vin*`

### Q: 图像颜色异常（偏色、偏绿）

**A**: 确认 `cvtColor` 使用的是 `COLOR_YUV2BGR_NV12` 而不是其他格式码。NV12 和 NV21 的 UV 排列不同，用错了会严重偏色。

### Q: reshape 报错

**A**: 确认 reshape 的高度是 `原始高度 × 1.5`。例如 1080p 图像：
- 正确：`reshape(1620, 1920)` — 1080 × 1.5 = 1620
- 错误：`reshape(1080, 1920)` — 数据量不够

### Q: 如何降低分辨率？

**A**: 在 `open_cam` 参数中指定更小的分辨率：

```python
cam.open_cam(0, -1, -1, [640], [480], 480, 640)
nv12 = cam.get_img(2, 640, 480)
nv12_array = np.frombuffer(nv12, dtype=np.uint8).reshape(720, 640)  # 480*1.5=720
```

---

*本教程基于 RDK X5 实际开发经验编写，代码经过实测验证。*

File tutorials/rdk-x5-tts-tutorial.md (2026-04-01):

# RDK X5 edge-tts 语音合成：让你的机器人开口说话

> 完整实战教程 | edge-tts 安装配置 + 多语言多音色 + ALSA 播放 + 项目集成
> 
> 作者：张晓烨 | D-Robotics 开发者生态
> 
> 硬件平台：地瓜机器人 RDK X5

---

## 你将获得什么

让 RDK X5 开口说话：
- 使用 edge-tts 生成高质量语音（100+ 种音色）
- 通过 ALSA 播放语音
- 封装可复用的 TTS 模块
- 实现语音播报、通知、对话等功能

**为什么选 edge-tts？**
- 免费，无需 API Key
- 音质好（微软 Neural TTS 引擎）
- 支持中文、英文、日文等 100+ 种语言和音色
- 纯 Python 实现，pip 一键安装
- 轻量，不占用 BPU 或 GPU 资源

> **注意**：edge-tts 需要联网（调用微软 Edge 的 TTS 接口）。如果需要完全离线的 TTS，可以考虑 sherpa-onnx 的离线 TTS 模型。

---

## 目录

1. [安装与配置](#1-安装与配置)
2. [快速体验](#2-快速体验)
3. [音色选择](#3-音色选择)
4. [ALSA 音频播放](#4-alsa-音频播放)
5. [完整 TTS 模块](#5-完整-tts-模块)
6. [进阶用法](#6-进阶用法)
   - 6.1 语速/音调调节
   - 6.2 SSML 标记
   - 6.3 流式生成
   - 6.4 缓存优化
7. [项目集成示例](#7-项目集成示例)
8. [常见问题](#8-常见问题)

---

## 1. 安装与配置

### 安装 edge-tts

```bash
pip3 install edge-tts
```

### 安装 ffmpeg（音频格式转换）

```bash
apt-get install -y ffmpeg
```

### 确认 ALSA 播放设备

```bash
aplay -l
```

记住你的 USB 声卡设备号，例如 `plughw:0,0`。

---

## 2. 快速体验

### 命令行方式

```bash
# 生成语音文件
edge-tts --voice zh-CN-XiaoyiNeural --text "你好，我是RDK X5机器人" --write-media hello.mp3

# 转换格式（aplay 需要 WAV）
ffmpeg -y -i hello.mp3 -ar 48000 -ac 1 -f wav hello.wav

# 播放
aplay -D plughw:0,0 hello.wav
```

### Python 方式

```python
import subprocess

text = "你好，我是RDK X5机器人"
voice = "zh-CN-XiaoyiNeural"

# 生成 + 转换 + 播放
subprocess.run(["edge-tts", "--voice", voice, "--text", text, "--write-media", "/tmp/tts.mp3"])
subprocess.run(["ffmpeg", "-y", "-i", "/tmp/tts.mp3", "-ar", "48000", "-ac", "1", "-f", "wav", "/tmp/tts.wav"])
subprocess.run(["aplay", "-D", "plughw:0,0", "/tmp/tts.wav"])
```

---

## 3. 音色选择

### 列出所有可用音色

```bash
edge-tts --list-voices
```

### 推荐中文音色

| 音色 ID | 性别 | 风格 | 推荐场景 |
|---|---|---|---|
| `zh-CN-XiaoyiNeural` | 女 | 温暖亲切 | 日常对话、助手 |
| `zh-CN-YunxiNeural` | 男 | 年轻自然 | 日常对话、助手 |
| `zh-CN-YunjianNeural` | 男 | 沉稳专业 | 新闻播报、正式场合 |
| `zh-CN-XiaoxiaoNeural` | 女 | 活泼开朗 | 故事讲述、娱乐 |
| `zh-CN-YunyangNeural` | 男 | 新闻播音 | 播报、通知 |

### 英文音色

| 音色 ID | 性别 | 风格 |
|---|---|---|
| `en-US-JennyNeural` | 女 | 自然流畅 |
| `en-US-GuyNeural` | 男 | 沉稳 |
| `en-GB-SoniaNeural` | 女 | 英式英语 |

### 试听和选择

```python
import subprocess

voices = [
    ("zh-CN-XiaoyiNeural", "小伊"),
    ("zh-CN-YunxiNeural", "云希"),
    ("zh-CN-XiaoxiaoNeural", "晓晓"),
]

for voice_id, name in voices:
    print(f"正在播放: {name} ({voice_id})")
    subprocess.run(["edge-tts", "--voice", voice_id,
                    "--text", f"你好，我是{name}，很高兴认识你",
                    "--write-media", "/tmp/test_voice.mp3"],
                   capture_output=True)
    subprocess.run(["ffmpeg", "-y", "-i", "/tmp/test_voice.mp3",
                    "-ar", "48000", "-ac", "1", "-f", "wav",
                    "/tmp/test_voice.wav"],
                   capture_output=True)
    subprocess.run(["aplay", "-D", "plughw:0,0", "/tmp/test_voice.wav"],
                   capture_output=True)
    import time
    time.sleep(0.5)
```

---

## 4. ALSA 音频播放

### 为什么需要格式转换？

edge-tts 输出 MP3 格式，但 ALSA 的 `aplay` 只支持 WAV/PCM。需要用 ffmpeg 转换。

### 播放参数

```bash
aplay -D plughw:0,0 output.wav
```

- `-D plughw:0,0`：指定播放设备
- `plughw` 会自动做采样率转换，比 `hw` 更兼容

### 调节音量

```bash
# 安装 alsa-utils（通常已预装）
alsamixer
# 选择声卡，调节 Master/Speaker 音量
```

或命令行：

```bash
amixer -c 0 set Master 80%
```

---

## 5. 完整 TTS 模块

一个可直接集成到项目中的 TTS 模块：

```python
#!/usr/bin/env python3
"""
RDK X5 TTS 模块
使用 edge-tts + ffmpeg + ALSA 实现语音合成和播放
"""
import os
import subprocess
import tempfile
import hashlib

class TTS:
    """语音合成器"""
    
    def __init__(self, voice="zh-CN-XiaoyiNeural", device="plughw:0,0",
                 cache_dir="/tmp/tts_cache"):
        self.voice = voice
        self.device = device
        self.cache_dir = cache_dir
        if cache_dir:
            os.makedirs(cache_dir, exist_ok=True)
    
    def speak(self, text, block=True):
        """
        合成并播放语音
        Args:
            text: 要朗读的文本
            block: 是否阻塞等待播放完成
        """
        if not text or not text.strip():
            return
        
        wav_path = self._get_or_generate(text)
        if wav_path is None:
            return
        
        cmd = ["aplay", "-D", self.device, wav_path]
        if block:
            subprocess.run(cmd, capture_output=True, timeout=600)
        else:
            subprocess.Popen(cmd, stdout=subprocess.DEVNULL,
                           stderr=subprocess.DEVNULL)
    
    def generate(self, text, output_path):
        """只生成 WAV 文件，不播放"""
        mp3_path = output_path + ".mp3"
        try:
            subprocess.run(
                ["edge-tts", "--voice", self.voice,
                 "--text", text, "--write-media", mp3_path],
                capture_output=True, timeout=30,
            )
            subprocess.run(
                ["ffmpeg", "-y", "-i", mp3_path,
                 "-ar", "48000", "-ac", "1", "-f", "wav", output_path],
                capture_output=True, timeout=15,
            )
            return True
        except Exception as e:
            print(f"[TTS Error] {e}")
            return False
        finally:
            try:
                os.unlink(mp3_path)
            except OSError:
                pass
    
    def _get_or_generate(self, text):
        """带缓存的语音生成"""
        if self.cache_dir:
            # 基于文本和音色生成缓存 key
            key = hashlib.md5(
                f"{self.voice}:{text}".encode()
            ).hexdigest()[:12]
            wav_path = os.path.join(self.cache_dir, f"{key}.wav")
            
            if os.path.exists(wav_path):
                return wav_path
        else:
            wav_path = tempfile.mktemp(suffix=".wav")
        
        if self.generate(text, wav_path):
            return wav_path
        return None
    
    def clear_cache(self):
        """清除缓存"""
        if self.cache_dir and os.path.exists(self.cache_dir):
            for f in os.listdir(self.cache_dir):
                if f.endswith(".wav"):
                    os.unlink(os.path.join(self.cache_dir, f))

# 使用示例
if __name__ == "__main__":
    tts = TTS(voice="zh-CN-XiaoyiNeural")
    
    # 基本使用
    tts.speak("你好，我是RDK X5机器人")
    
    # 第二次调用同样文本会使用缓存，瞬间播放
    tts.speak("你好，我是RDK X5机器人")
    
    # 切换音色
    tts_male = TTS(voice="zh-CN-YunxiNeural")
    tts_male.speak("你好，我是男声助手")
    
    # 非阻塞播放
    tts.speak("这句话在后台播放", block=False)
    print("主线程继续执行...")
```

---

## 6. 进阶用法

### 6.1 语速和音调调节

```bash
# 加速 20%
edge-tts --voice zh-CN-XiaoyiNeural --rate="+20%" --text "说话加速" --write-media fast.mp3

# 减速 30%
edge-tts --voice zh-CN-XiaoyiNeural --rate="-30%" --text "说话减速" --write-media slow.mp3

# 提高音调
edge-tts --voice zh-CN-XiaoyiNeural --pitch="+10Hz" --text "声音变高" --write-media high.mp3
```

Python 中：

```python
subprocess.run([
    "edge-tts",
    "--voice", "zh-CN-XiaoyiNeural",
    "--rate", "+15%",       # 语速
    "--pitch", "+5Hz",      # 音调
    "--volume", "+20%",     # 音量
    "--text", "调整后的语音",
    "--write-media", "/tmp/adjusted.mp3"
])
```

### 6.2 SSML 标记语言

对于需要精细控制的场景，可以使用 SSML：

```python
import asyncio
import edge_tts

async def ssml_speak():
    ssml = """
    <speak version="1.0" xmlns="http://www.w3.org/2001/10/synthesis" xml:lang="zh-CN">
        <voice name="zh-CN-XiaoyiNeural">
            <prosody rate="medium" pitch="medium">
                你好！
                <break time="500ms"/>
                欢迎来到RDK X5的世界。
                <emphasis level="strong">这是重点内容。</emphasis>
            </prosody>
        </voice>
    </speak>
    """
    communicate = edge_tts.Communicate(ssml, voice="zh-CN-XiaoyiNeural")
    await communicate.save("/tmp/ssml_output.mp3")

asyncio.run(ssml_speak())
```

### 6.3 流式生成

对于长文本，可以流式生成并逐段播放，减少首次响应延迟：

```python
import asyncio
import edge_tts

async def stream_tts(text, voice="zh-CN-XiaoyiNeural"):
    communicate = edge_tts.Communicate(text, voice)
    
    with open("/tmp/stream.mp3", "wb") as f:
        async for chunk in communicate.stream():
            if chunk["type"] == "audio":
                f.write(chunk["data"])

asyncio.run(stream_tts("这是一段很长的文本，流式生成可以更快开始播放。"))
```

### 6.4 缓存优化

对于固定的语音（如提示音、欢迎语），在启动时预生成缓存：

```python
# 启动时预缓存常用语音
PRELOAD_PHRASES = [
    "在呢",
    "好的",
    "收到",
    "正在处理",
    "完成了",
    "抱歉，我没听清",
]

tts = TTS()
for phrase in PRELOAD_PHRASES:
    tts._get_or_generate(phrase)  # 预生成缓存

print("常用语音已缓存，后续播放无延迟")
```

---

## 7. 项目集成示例

### 天气播报

```python
def announce_weather(tts, weather_info):
    text = f"今天{weather_info['city']}的天气{weather_info['condition']}，" \
           f"气温{weather_info['temp_low']}到{weather_info['temp_high']}度。"
    if "雨" in weather_info['condition']:
        text += "记得带伞。"
    tts.speak(text)
```

### 定时提醒

```python
import time
from datetime import datetime

tts = TTS()

reminders = [
    ("10:00", "该站起来活动一下了"),
    ("12:00", "午饭时间到了"),
    ("18:00", "下班时间到了，辛苦了"),
]

while True:
    now = datetime.now().strftime("%H:%M")
    for reminder_time, message in reminders:
        if now == reminder_time:
            tts.speak(message)
    time.sleep(60)
```

### 语音交互助手

```python
# 语音助手中的 TTS 集成
class VoiceAssistant:
    def __init__(self):
        self.tts = TTS(voice="zh-CN-XiaoyiNeural")
        # ... 其他初始化 ...
    
    def respond(self, ai_reply):
        """播放 AI 回复"""
        # 清理 markdown 格式（TTS 不需要）
        clean_text = ai_reply.replace("**", "").replace("*", "")
        clean_text = clean_text.replace("#", "").replace("`", "")
        
        # 截取最后一段（避免播放太长）
        if "\n" in clean_text:
            clean_text = clean_text.split("\n")[-1]
        
        self.tts.speak(clean_text)
```

---

## 8. 常见问题

### Q: edge-tts 报网络错误

**A**: edge-tts 需要联网。检查网络连接：
```bash
ping -c 3 speech.platform.bing.com
```
如果网络不可用，考虑使用 sherpa-onnx 的离线 TTS。

### Q: 播放有杂音或卡顿

**A**: 
- 检查 USB 声卡连接是否稳固
- 尝试调整采样率：`-ar 44100` 或 `-ar 16000`
- 避免同时录音和播放

### Q: 如何减少首次播放延迟？

**A**: 三个策略：
1. **预缓存**：启动时预生成常用语音
2. **降低采样率**：`-ar 16000` 比 `-ar 48000` 文件更小
3. **流式处理**：边生成边播放（需要用 async API）

### Q: 中英文混合怎么办？

**A**: edge-tts 支持中英文混合朗读，无需特殊处理：
```python
tts.speak("今天的temperature是25度，very comfortable")
```

### Q: 能否完全离线？

**A**: edge-tts 本身不支持离线。离线方案：
- sherpa-onnx 的离线 TTS 模型（中文可用 vits-zh）
- piper TTS（开源离线方案）
- 预生成所有可能的语音并缓存

---

*本教程基于 RDK X5 实际开发经验编写，代码经过实测验证。*

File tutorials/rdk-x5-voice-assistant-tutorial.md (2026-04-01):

# 从零开始：在 RDK X5 上搭建离线语音助手

> 完整实战教程 | 唤醒词检测 + 语音识别 + AI 对话 + 语音合成
> 
> 作者：张晓烨 | D-Robotics 开发者生态
> 
> 硬件平台：地瓜机器人 RDK X5

---

## 你将获得什么

一个完整的离线语音助手系统：
- 说出唤醒词"五五零"，机器人回应"在呢"
- 然后说出你的指令，机器人识别后通过 AI 生成回答
- 最后用语音把回答读给你听

整个语音识别过程**完全离线运行**，不依赖任何云端 API。AI 对话部分可以对接任意大模型后端。

**技术栈：**
- **VAD（语音活动检测）**：Silero VAD — 轻量级，适合边缘设备
- **ASR（语音识别）**：SenseVoice — 阿里达摩院开源，支持中英日韩粤
- **推理框架**：sherpa-onnx — 新一代纯 C++ 推理引擎，原生支持 ARM
- **TTS（语音合成）**：edge-tts — 微软 Edge 浏览器 TTS 接口
- **音频采集/播放**：ALSA — Linux 原生音频驱动

---

## 目录

1. [硬件准备](#1-硬件准备)
2. [系统环境配置](#2-系统环境配置)
3. [安装依赖](#3-安装依赖)
4. [下载模型文件](#4-下载模型文件)
5. [音频设备测试](#5-音频设备测试)
6. [核心代码详解](#6-核心代码详解)
   - 6.1 VAD 语音活动检测
   - 6.2 ASR 语音识别
   - 6.3 唤醒词匹配
   - 6.4 音频采集架构
   - 6.5 TTS 语音合成
   - 6.6 完整交互流程
7. [完整代码](#7-完整代码)
8. [运行与测试](#8-运行与测试)
9. [常见问题与踩坑记录](#9-常见问题与踩坑记录)
10. [进阶优化方向](#10-进阶优化方向)

---

## 1. 硬件准备

| 硬件 | 说明 |
|---|---|
| RDK X5 开发板 | 地瓜机器人出品，ARM aarch64，8GB 内存 |
| USB 声卡模块 | 推荐带麦克风+扬声器的一体模块（如 Jieli UACDemoV1.0） |
| 麦克风 | USB 声卡自带或外接 |
| 扬声器 | USB 声卡自带或 3.5mm 外接 |

> **为什么用 USB 声卡？** RDK X5 板载的 ES8326 音频芯片虽然支持双工，但实测在同时录音+播放场景下稳定性不如 USB 声卡。USB 声卡即插即用，驱动兼容性好。

---

## 2. 系统环境配置

RDK X5 默认运行 Ubuntu 系统（aarch64），Python 3.10+。

```bash
# 确认系统信息
uname -a
# Linux ubuntu 6.1.83 ... aarch64

python3 --version
# Python 3.10.12
```

建议使用清华 pip 镜像源加速下载：

```bash
pip3 config set global.index-url https://pypi.tuna.tsinghua.edu.cn/simple
```

---

## 3. 安装依赖

### 3.1 sherpa-onnx

sherpa-onnx 是由 [k2-fsa/sherpa-onnx](https://github.com/k2-fsa/sherpa-onnx) 提供的推理框架，原生支持 ARM 架构，集成了 VAD、ASR、TTS 等功能。

```bash
pip3 install sherpa-onnx
```

> **版本说明**：本教程使用 sherpa-onnx 1.12.30，API 可能随版本变化。

sherpa-onnx 自带 ALSA 音频采集接口（`sherpa_onnx.Alsa`），不需要安装 pyaudio。

> **踩坑提醒**：RDK X5 默认没有 `portaudio19-dev`，安装 pyaudio 会失败。直接用 sherpa-onnx 自带的 Alsa 类即可。

### 3.2 edge-tts

```bash
pip3 install edge-tts
```

### 3.3 ffmpeg

```bash
apt-get install -y ffmpeg
```

### 3.4 其他 Python 依赖

```bash
pip3 install numpy
```

---

## 4. 下载模型文件

需要两个模型：

### 4.1 Silero VAD 模型

Silero VAD 是一个极轻量的语音活动检测模型（仅 629KB），非常适合边缘设备。

```bash
mkdir -p models
wget -O models/silero_vad.onnx \
  https://github.com/snakers4/silero-vad/raw/master/files/silero_vad.onnx
```

### 4.2 SenseVoice ASR 模型

SenseVoice 是阿里达摩院开源的多语言语音识别模型，支持中、英、日、韩、粤五种语言。我们使用 INT8 量化版本（约 229MB），在 RDK X5 上推理速度很快。

```bash
# 从 HuggingFace 下载（如果网络慢，可以用镜像）
wget https://github.com/k2-fsa/sherpa-onnx/releases/download/asr-models/sherpa-onnx-sense-voice-zh-en-ja-ko-yue-2024-07-17.tar.bz2

# 解压到 models 目录
tar xjf sherpa-onnx-sense-voice-zh-en-ja-ko-yue-2024-07-17.tar.bz2 -C models/
```

> **注意**：在 RDK X5 上从 GitHub 下载速度可能只有 ~700KB/s，229MB 的模型需要耐心等待约 5 分钟。建议提前在电脑上下载好再传到板子上。

最终目录结构：

```
models/
├── silero_vad.onnx                                          (629K)
└── sherpa-onnx-sense-voice-zh-en-ja-ko-yue-2024-07-17/
    ├── model.int8.onnx                                      (229M)
    └── tokens.txt
```

---

## 5. 音频设备测试

### 5.1 查看声卡

```bash
aplay -l   # 查看播放设备
arecord -l  # 查看录音设备
```

你应该能看到类似输出：

```
card 0: UACDemoV1.0 [USB audio]
card 1: ES8326 [onboard]
```

### 5.2 测试录音和播放

```bash
# 录制 3 秒音频
arecord -D plughw:0,0 -f S16_LE -r 16000 -c 1 -d 3 test.wav

# 播放
aplay -D plughw:0,0 test.wav
```

如果能听到自己的声音，说明音频设备工作正常。

> **设备号说明**：`plughw:0,0` 表示第 0 张声卡的第 0 个设备。如果你的 USB 声卡不是 card 0，需要相应调整。

---

## 6. 核心代码详解

### 6.1 VAD — 语音活动检测

VAD 的作用是从连续的音频流中检测出"有人在说话"的片段。我们用 Silero VAD，它的优势是体积小、速度快、准确率高。

```python
import sherpa_onnx

def create_vad():
    config = sherpa_onnx.VadModelConfig()
    config.silero_vad.model = "models/silero_vad.onnx"
    config.silero_vad.threshold = 0.5          # 语音检测阈值
    config.silero_vad.min_silence_duration = 0.5  # 最小静音时长（秒）
    config.silero_vad.min_speech_duration = 0.25  # 最小语音时长（秒）
    config.sample_rate = 16000
    
    vad = sherpa_onnx.VoiceActivityDetector(config, buffer_size_in_seconds=30)
    return vad
```

**参数解释：**
- `threshold`：语音概率阈值，越高越严格（减少误触发），越低越灵敏
- `min_silence_duration`：说话停顿多久算"说完了"
- `min_speech_duration`：最短语音段长度，过短的会被过滤掉

**使用方式：**

```python
# 持续喂入音频数据
vad.accept_waveform(audio_chunk)  # float32 numpy array

# 检查是否有完整的语音段
if not vad.empty():
    segment = vad.front       # 获取语音段
    samples = segment.samples # float32 音频数据
    vad.pop()                 # 弹出已处理的段
```

### 6.2 ASR — 语音识别

SenseVoice 支持离线语音识别，在 RDK X5 上使用 INT8 量化模型推理。

```python
def create_asr():
    model_dir = "models/sherpa-onnx-sense-voice-zh-en-ja-ko-yue-2024-07-17"
    recognizer = sherpa_onnx.OfflineRecognizer.from_sense_voice(
        model=f"{model_dir}/model.int8.onnx",
        tokens=f"{model_dir}/tokens.txt",
        language="zh",
        use_itn=True,     # 启用逆文本正则化（数字转阿拉伯数字等）
        num_threads=2,     # 推理线程数
    )
    return recognizer
```

> **重要**：必须使用工厂方法 `from_sense_voice()` 创建识别器，不能直接传 config 构造。这是 sherpa-onnx 针对 SenseVoice 模型的专用接口。

**识别流程：**

```python
import re
import numpy as np

def recognize(recognizer, samples):
    stream = recognizer.create_stream()
    
    # 确保数据是 [-1, 1] 范围的 float32
    normalized = samples.astype(np.float32)
    
    stream.accept_waveform(16000, normalized.tolist())
    recognizer.decode_stream(stream)
    
    text = stream.result.text.strip()
    # SenseVoice 会在结果前加语言/情感标签，需要清除
    text = re.sub(r'<\|[^|]*\|>', '', text).strip()
    return text
```

SenseVoice 的输出格式类似：`<|zh|><|NEUTRAL|><|Speech|>你好世界`，需要用正则清理掉标签。

### 6.3 唤醒词匹配

传统的唤醒词检测需要专用的 KWS（Keyword Spotting）模型。但在 RDK X5 上，我们采用了一个更实用的方案：**VAD + ASR 文本匹配**。

原理很简单：
1. VAD 检测到有人说话
2. ASR 识别出文字
3. 检查文字里是否包含唤醒词

```python
WAKE_PATTERNS = [
    "五五零", "550", "五五〇", "五五领", "五五灵",
    "五五令", "五五另", "wu wu ling", "五50",
]

def is_wake_word(text):
    text_lower = text.lower().replace(" ", "")
    for pattern in WAKE_PATTERNS:
        if pattern.lower().replace(" ", "") in text_lower:
            return True
    return False
```

**为什么要这么多变体？** 因为 ASR 模型对短词的识别不是 100% 准确的，"五五零"可能被识别成"五五领""五五灵"等同音词。列出常见的误识别变体可以大幅提高唤醒成功率。

> **踩坑记录**：我们最初尝试用 sherpa-onnx 的专用 KWS 模型（zipformer transducer），但 GitHub 下载速度太慢（模型很大），最终改用 VAD+ASR 文本匹配方案。实测效果完全够用，而且更灵活 — 改唤醒词只需要改字符串，不需要重新训练模型。

### 6.4 音频采集架构

这是整个系统中最容易出问题的部分。关键设计：

**后台线程持续读取 ALSA 缓冲区：**

```python
import queue

class VoiceAssistant:
    def __init__(self):
        self.alsa = sherpa_onnx.Alsa("plughw:0,0")
        self.is_speaking = False
        self._audio_queue = queue.Queue(maxsize=200)  # ~20 秒缓冲
        
        # 启动后台读取线程
        self._reader_thread = threading.Thread(
            target=self._alsa_reader_loop, daemon=True
        )
        self._reader_thread.start()
    
    def _alsa_reader_loop(self):
        samples_per_read = int(16000 * 0.1)  # 每次读 100ms
        while True:
            samples = self.alsa.read(samples_per_read)
            if self.is_speaking:
                continue  # TTS 播放时丢弃音频，避免自触发
            try:
                self._audio_queue.put_nowait(samples)
            except queue.Full:
                # 队列满了，丢掉最旧的数据
                self._audio_queue.get_nowait()
                self._audio_queue.put_nowait(samples)
```

**为什么需要后台线程？**

ALSA 的硬件缓冲区是有限的。如果主线程在处理 ASR 或等待 AI 回复时不读取音频数据，ALSA 缓冲区会溢出（overrun），导致后续数据丢失甚至设备错误。

后台线程确保无论主线程在做什么，音频数据都在持续被读取。

**TTS 期间静音处理：**

播放语音回复时，麦克风会采集到扬声器的声音。如果不处理，系统会识别到自己说的话，产生"自触发"。解决方案：

```python
if self.is_speaking:
    continue  # 直接丢弃
```

播放结束后清空队列中残留的音频：

```python
def _drain_queue(self):
    while not self._audio_queue.empty():
        self._audio_queue.get_nowait()
```

### 6.5 TTS — 语音合成

使用 edge-tts 将文字转为语音，再通过 ALSA 播放：

```python
import subprocess
import tempfile

TTS_VOICE = "zh-CN-XiaoyiNeural"  # 微软小伊

def speak(text):
    if not text:
        return
    
    with tempfile.NamedTemporaryFile(suffix=".mp3", delete=False) as f:
        mp3_path = f.name
    wav_path = mp3_path.replace(".mp3", ".wav")
    
    try:
        # 1. edge-tts 生成 MP3
        subprocess.run([
            "edge-tts", "--voice", TTS_VOICE,
            "--text", text, "--write-media", mp3_path
        ], capture_output=True, timeout=30)
        
        # 2. ffmpeg 转换为 WAV（ALSA 需要 WAV 格式）
        subprocess.run([
            "ffmpeg", "-y", "-i", mp3_path,
            "-ar", "48000", "-ac", "1", "-f", "wav", wav_path
        ], capture_output=True, timeout=15)
        
        # 3. aplay 播放
        subprocess.run([
            "aplay", "-D", "plughw:0,0", wav_path
        ], capture_output=True, timeout=600)
    finally:
        # 清理临时文件
        for p in [mp3_path, wav_path]:
            try:
                os.unlink(p)
            except:
                pass
```

> **优化技巧**：对于固定的回复（如唤醒回应"在呢"），可以在启动时预生成音频文件缓存，避免每次都调用 edge-tts，大幅减少响应延迟。

### 6.6 完整交互流程

```
┌──────────────────────────────────────────────────────┐
│                   主循环 (listen_loop)                 │
│                                                       │
│  ┌─────────────┐                                     │
│  │ 后台线程持续  │──→ audio_queue ──→ VAD 检测         │
│  │ 读取 ALSA    │                                     │
│  └─────────────┘                                     │
│                                                       │
│  VAD 检测到语音段 → ASR 识别                           │
│       │                                               │
│       ├── 包含唤醒词？                                 │
│       │    ├── 唤醒词后有内容 → 直接处理命令            │
│       │    └── 只有唤醒词 → 回应"在呢" → 等待命令      │
│       │                                               │
│       │    ┌── listen_for_command ──┐                 │
│       │    │  播放"叮"提示音         │                 │
│       │    │  等待用户说话           │                 │
│       │    │  VAD 检测 + ASR 识别    │                 │
│       │    │  播放"咚"结束音         │                 │
│       │    └────────────────────────┘                 │
│       │                                               │
│       └── handle_command                              │
│            │                                          │
│            ├── 发送到 AI 后端                          │
│            ├── 获取回复                                │
│            └── TTS 播放回复                            │
│                                                       │
└──────────────────────────────────────────────────────┘
```

**两种唤醒模式：**

1. **唤醒词 + 命令一起说**：比如"五五零，今天天气怎么样" — 直接识别并处理
2. **先唤醒再说命令**：先说"五五零"，听到"在呢"和提示音后，再说命令

---

## 7. 完整代码

将以下代码保存为 `voice_assistant.py`：

```python
#!/usr/bin/env python3
"""
RDK X5 离线语音助手
- Silero VAD 语音活动检测
- SenseVoice ASR 语音识别
- 唤醒词文本匹配
- edge-tts 语音合成
"""

import os
import sys
import time
import subprocess
import tempfile
import threading
import re
import queue
import numpy as np
import sherpa_onnx

# ── 配置 ──────────────────────────────────────────────────
MODELS_DIR = os.path.join(os.path.dirname(os.path.abspath(__file__)), "models")
SAMPLE_RATE = 16000
ALSA_DEVICE = "plughw:0,0"
PLAYBACK_DEVICE = "plughw:0,0"
TTS_VOICE = "zh-CN-XiaoyiNeural"

# 唤醒词及其常见误识别变体
WAKE_PATTERNS = [
    "五五零", "550", "五五〇", "五五领", "五五灵",
    "五五令", "五五另", "wu wu ling", "五50",
]

# VAD 参数
VAD_THRESHOLD = 0.5
VAD_MIN_SILENCE_MS = 500
VAD_MIN_SPEECH_MS = 250

# 超时参数
WAKE_LISTEN_TIMEOUT = 15.0   # 唤醒后等待命令的最长时间
POST_SPEECH_SILENCE = 1.5    # 说完话后的静默判定时间

def create_vad():
    config = sherpa_onnx.VadModelConfig()
    config.silero_vad.model = os.path.join(MODELS_DIR, "silero_vad.onnx")
    config.silero_vad.threshold = VAD_THRESHOLD
    config.silero_vad.min_silence_duration = VAD_MIN_SILENCE_MS / 1000.0
    config.silero_vad.min_speech_duration = VAD_MIN_SPEECH_MS / 1000.0
    config.sample_rate = SAMPLE_RATE
    return sherpa_onnx.VoiceActivityDetector(config, buffer_size_in_seconds=30)

def create_asr():
    model_dir = os.path.join(
        MODELS_DIR, "sherpa-onnx-sense-voice-zh-en-ja-ko-yue-2024-07-17"
    )
    return sherpa_onnx.OfflineRecognizer.from_sense_voice(
        model=os.path.join(model_dir, "model.int8.onnx"),
        tokens=os.path.join(model_dir, "tokens.txt"),
        language="zh",
        use_itn=True,
        num_threads=2,
    )

def recognize(recognizer, samples):
    stream = recognizer.create_stream()
    normalized = samples.astype(np.float32)
    # 如果数据范围不在 [-1, 1]，做归一化
    if float(np.max(np.abs(normalized))) > 1.1:
        normalized = normalized / 32768.0
    stream.accept_waveform(SAMPLE_RATE, normalized.tolist())
    recognizer.decode_stream(stream)
    text = stream.result.text.strip()
    text = re.sub(r'<\|[^|]*\|>', '', text).strip()
    return text

def is_wake_word(text):
    text_lower = text.lower().replace(" ", "")
    return any(
        p.lower().replace(" ", "") in text_lower
        for p in WAKE_PATTERNS
    )

def extract_command_after_wake(text):
    text_lower = text.lower().replace(" ", "")
    for pattern in WAKE_PATTERNS:
        p = pattern.lower().replace(" ", "")
        idx = text_lower.find(p)
        if idx >= 0:
            remaining = text[idx + len(pattern):].strip().lstrip(",，.。!！?？ ")
            return remaining
    return ""

def speak(text):
    if not text:
        return
    with tempfile.NamedTemporaryFile(suffix=".mp3", delete=False) as f:
        mp3_path = f.name
    wav_path = mp3_path.replace(".mp3", ".wav")
    try:
        subprocess.run(
            ["edge-tts", "--voice", TTS_VOICE, "--text", text,
             "--write-media", mp3_path],
            capture_output=True, timeout=30,
        )
        subprocess.run(
            ["ffmpeg", "-y", "-i", mp3_path,
             "-ar", "48000", "-ac", "1", "-f", "wav", wav_path],
            capture_output=True, timeout=15,
        )
        subprocess.run(
            ["aplay", "-D", PLAYBACK_DEVICE, wav_path],
            capture_output=True, timeout=600,
        )
    finally:
        for p in [mp3_path, wav_path]:
            try:
                os.unlink(p)
            except OSError:
                pass

def send_to_ai(text):
    """
    将用户指令发送到 AI 后端，获取回复。
    这里需要替换为你自己的 AI 接口调用。
    示例使用 OpenAI 兼容接口：
    """
    # === 替换为你的 AI 调用 ===
    # 最简单的方式：调用本地部署的大模型 API
    # 或者使用 requests 调用远程 API
    #
    # import requests
    # resp = requests.post("http://your-api/v1/chat/completions", json={
    #     "model": "your-model",
    #     "messages": [{"role": "user", "content": text}]
    # })
    # return resp.json()["choices"][0]["message"]["content"]
    
    return f"你说的是：{text}"  # 占位回复，替换为实际 AI 调用

class VoiceAssistant:
    def __init__(self):
        print("[Init] Loading models...")
        self.vad = create_vad()
        self.asr = create_asr()
        self.alsa = sherpa_onnx.Alsa(ALSA_DEVICE)
        self.is_speaking = False
        self._audio_queue = queue.Queue(maxsize=200)

        self._reader_thread = threading.Thread(
            target=self._alsa_reader_loop, daemon=True
        )
        self._reader_thread.start()

        # 预生成唤醒回应音频
        self.wake_wav = "/tmp/wake_response.wav"
        self._prepare_wake_audio()
        print("[Init] Ready! Say the wake word to start.")

    def _alsa_reader_loop(self):
        samples_per_read = int(SAMPLE_RATE * 0.1)
        while True:
            try:
                samples = self.alsa.read(samples_per_read)
                if len(samples) == 0:
                    time.sleep(0.005)
                    continue
                if self.is_speaking:
                    continue
                try:
                    self._audio_queue.put_nowait(samples)
                except queue.Full:
                    try:
                        self._audio_queue.get_nowait()
                    except queue.Empty:
                        pass
                    self._audio_queue.put_nowait(samples)
            except Exception as e:
                print(f"[Reader] Error: {e}")
                time.sleep(0.1)

    def _drain_queue(self):
        while not self._audio_queue.empty():
            try:
                self._audio_queue.get_nowait()
            except queue.Empty:
                break

    def _prepare_wake_audio(self):
        try:
            mp3_path = "/tmp/wake_response.mp3"
            subprocess.run(
                ["edge-tts", "--voice", TTS_VOICE, "--text", "在呢",
                 "--write-media", mp3_path],
                capture_output=True, timeout=30,
            )
            subprocess.run(
                ["ffmpeg", "-y", "-i", mp3_path, "-ar", "48000",
                 "-ac", "1", "-f", "wav", self.wake_wav],
                capture_output=True, timeout=15,
            )
            os.unlink(mp3_path)
        except Exception as e:
            print(f"[Init] Wake audio failed: {e}")
            self.wake_wav = None

    def _speak_wake(self):
        if self.wake_wav and os.path.exists(self.wake_wav):
            self.is_speaking = True
            try:
                subprocess.run(
                    ["aplay", "-D", PLAYBACK_DEVICE, self.wake_wav],
                    capture_output=True, timeout=10,
                )
            finally:
                self.is_speaking = False
                self._drain_queue()
        else:
            self.is_speaking = True
            speak("在呢")
            self.is_speaking = False
            self._drain_queue()

    def listen_loop(self):
        while True:
            try:
                try:
                    samples = self._audio_queue.get(timeout=0.5)
                except queue.Empty:
                    continue

                arr = np.array(samples, dtype=np.float32)
                self.vad.accept_waveform(arr)

                while not self.vad.empty():
                    segment = self.vad.front
                    audio = np.array(segment.samples, dtype=np.float32).copy()
                    self.vad.pop()

                    if len(audio) < SAMPLE_RATE * 0.3:
                        continue

                    text = recognize(self.asr, audio)
                    if not text:
                        continue

                    print(f"[Heard] {text}")

                    if is_wake_word(text):
                        cmd = extract_command_after_wake(text)
                        if cmd and len(cmd) > 1:
                            self.handle_command(cmd)
                        else:
                            self._speak_wake()
                            self.vad.reset()
                            time.sleep(0.3)
                            self.listen_for_command()

            except KeyboardInterrupt:
                break
            except Exception as e:
                print(f"[Error] {e}")
                time.sleep(0.5)

    def listen_for_command(self):
        print("[Listen] Waiting for command...")
        self._drain_queue()
        self.vad.reset()

        start_time = time.time()
        speech_started = False
        silence_start = None

        while time.time() - start_time < WAKE_LISTEN_TIMEOUT:
            try:
                samples = self._audio_queue.get(timeout=0.5)
            except queue.Empty:
                if speech_started and silence_start is None:
                    silence_start = time.time()
                if silence_start and time.time() - silence_start >= POST_SPEECH_SILENCE:
                    break
                continue

            arr = np.array(samples, dtype=np.float32)
            self.vad.accept_waveform(arr)

            energy = float(np.max(np.abs(arr)))
            if energy > 0.05:
                speech_started = True
                silence_start = None
            elif speech_started:
                if silence_start is None:
                    silence_start = time.time()
                elif time.time() - silence_start >= POST_SPEECH_SILENCE:
                    break

        if not speech_started:
            print("[Listen] No command heard.")
            return

        collected = []
        while not self.vad.empty():
            seg = self.vad.front
            seg_audio = np.array(seg.samples, dtype=np.float32).copy()
            self.vad.pop()
            if len(seg_audio) >= SAMPLE_RATE * 0.3:
                collected.append(seg_audio)

        if not collected:
            return

        audio = np.concatenate(collected)
        text = recognize(self.asr, audio)
        if text:
            self.handle_command(text)

    def handle_command(self, text):
        print(f"[Command] {text}")
        response = send_to_ai(text)
        if response:
            self.is_speaking = True
            speak(response)
            self.is_speaking = False
            self._drain_queue()

def main():
    # 检查模型文件
    vad_model = os.path.join(MODELS_DIR, "silero_vad.onnx")
    sv_dir = os.path.join(
        MODELS_DIR, "sherpa-onnx-sense-voice-zh-en-ja-ko-yue-2024-07-17"
    )
    if not os.path.exists(vad_model):
        print(f"VAD model not found: {vad_model}")
        sys.exit(1)
    if not os.path.exists(sv_dir):
        print(f"SenseVoice model not found: {sv_dir}")
        sys.exit(1)

    assistant = VoiceAssistant()
    assistant.listen_loop()

if __name__ == "__main__":
    main()
```

---

## 8. 运行与测试

### 8.1 直接运行

```bash
python3 voice_assistant.py
```

你应该看到：

```
[Init] Loading models...
[Init] Wake response audio ready.
[Init] Ready! Say the wake word to start.
```

### 8.2 后台运行（推荐）

创建启动脚本 `start.sh`：

```bash
#!/bin/bash
cd "$(dirname "$0")"
echo "Voice assistant launcher (auto-restart on crash)"
while true; do
    echo "[$(date)] Starting voice_assistant.py ..."
    python3 -u voice_assistant.py 2>&1 | tee -a /tmp/voice-assistant.log
    echo "[$(date)] Process exited ($?), restarting in 3s..."
    sleep 3
done
```

```bash
chmod +x start.sh
nohup ./start.sh &
```

### 8.3 测试流程

1. 对着麦克风说"五五零"
2. 听到"在呢"回应
3. 说出你的指令（如"今天天气怎么样"）
4. 等待 AI 回复并语音播放

---

## 9. 常见问题与踩坑记录

### Q: pyaudio 安装失败

```
ERROR: No matching distribution found for pyaudio
```

**A**: RDK X5 缺少 `portaudio19-dev` 依赖。不需要装 pyaudio，直接用 `sherpa_onnx.Alsa`。

### Q: ASR 识别结果有奇怪的标签

识别结果类似：`<|zh|><|NEUTRAL|><|Speech|>你好`

**A**: 这是 SenseVoice 模型的输出格式。用正则清除：

```python
text = re.sub(r'<\|[^|]*\|>', '', text).strip()
```

### Q: 机器人会被自己说的话触发

**A**: 在 TTS 播放时设置 `is_speaking = True`，后台线程检测到这个标志就丢弃采集到的音频。播放结束后清空队列。

### Q: ALSA buffer overrun

```
ALSA lib pcm.c:xxx underrun occurred
```

**A**: 确保后台线程在持续读取音频数据。如果主线程阻塞太久（比如等待 AI 回复），后台线程会继续读取，避免溢出。

### Q: GitHub 下载模型太慢

**A**: 在 RDK X5 上下载 GitHub 文件可能只有 ~700KB/s。建议：
- 在电脑上下载好，用 `scp` 传到板子
- 或使用 HuggingFace 镜像站

### Q: 识别准确率不高

**A**: 检查以下几点：
- 麦克风是否距离太远（建议 50cm 以内）
- 环境噪音是否太大
- USB 声卡的录音增益是否合适（可以用 `alsamixer` 调节）
- VAD threshold 是否需要调整

---

## 10. 进阶优化方向

### 10.1 会话管理

为语音交互添加会话概念 — 一段时间内的对话共享上下文：

```python
SESSION_GAP_SECONDS = 30 * 60  # 30 分钟无交互开启新会话

def get_session_id():
    # 读取上次交互时间
    # 如果间隔 < 30 分钟，复用会话
    # 否则创建新会话
    ...
```

### 10.2 提示音反馈

添加"叮"和"咚"提示音，让用户知道系统什么时候在听：
- "叮" — 开始录音
- "咚" — 录音结束，开始处理

### 10.3 流式 TTS

当前方案是先完整生成回复，再一次性 TTS。可以改为流式：AI 生成一句就 TTS 播放一句，大幅减少等待感。

### 10.4 多语言支持

SenseVoice 本身支持中英日韩粤五种语言，只需修改 `language` 参数或设为自动检测即可。

### 10.5 声纹识别

添加声纹验证，只响应特定用户的唤醒词，避免被其他人误触发。sherpa-onnx 也提供了 speaker identification 相关的模型。

---

## 写在最后

这个项目展示了在 RDK X5 这样的边缘 AI 开发板上，完全可以构建一个实用的离线语音助手。核心的 VAD + ASR 全部在本地运行，响应速度快，不依赖网络。

完整代码和模型都是开源的：
- sherpa-onnx: https://github.com/k2-fsa/sherpa-onnx
- Silero VAD: https://github.com/snakers4/silero-vad
- SenseVoice: https://github.com/FunAudioLLM/SenseVoice
- edge-tts: https://github.com/rany2/edge-tts

如果你也在 RDK X5 或其他 ARM 设备上做语音交互项目，欢迎交流。

---

*本教程基于实际运行在 RDK X5 上的项目编写，所有代码均经过实测验证。*

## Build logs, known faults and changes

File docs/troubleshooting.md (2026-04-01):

# 踩坑指南 (Troubleshooting)

这些都是实际调试中踩过的坑，能帮你省很多时间。

---

## 音频相关

### USB 麦克风必须开启 AGC

**症状：** 语音助手启动正常，但 VAD 永远检测不到语音。

**原因：** USB 麦克风的 Auto Gain Control (AGC) 关闭时，采集信号极弱（max ~0.03~0.09），Silero VAD 无法触发。

**解决：**
```bash
# 检查当前设置
amixer -c 0 contents

# 开启 AGC + 增益拉满
amixer -c 0 set 'Auto Gain Control' on
amixer -c 0 set 'Mic' 147
```

**注意：** amixer 设置重启后可能丢失！用 `alsactl store` 持久化，或在 systemd service 里加 ExecStartPre。

### USB 声卡不能同时录音和播放

**症状：** TTS 播放期间或播放后，录音数据变成全零/固定值。

**原因：** plughw:0,0 不支持全双工。arecord 和 aplay 同时打开同一个设备，capture 数据会被污染。

**解决：** 播放前 kill arecord 进程，播放完后再重启。代码里用 `is_speaking` 标志控制：
```python
# 播放前
is_speaking = True
# kill arecord subprocess

# 播放后
is_speaking = False
# reader 线程检测到 is_speaking=False 后重启 arecord
```

**隐蔽性：** 这个 bug 不会报错！arecord 正常启动、正常读数据，但数据全是无效固定值。只能通过观察数据异常发现。

### sherpa_onnx.Alsa 不可靠

**症状：** 间歇性返回固定值/陈旧数据，特别是 TTS 播放后。

**解决：** 弃用 `sherpa_onnx.Alsa`，改用 `subprocess.Popen` 跑 arecord：
```bash
arecord -D plughw:0,0 -f S16_LE -r 16000 -c 1 -t raw
```
用 reader 线程持续读取 stdout。

### 排查音频问题的正确顺序

1. 先查 ALSA mixer 设置（`amixer -c 0 contents`）
2. 再测直接采集（用 arecord 录一段，看波形）
3. 最后才看代码逻辑

不要一上来就改代码阈值或回退版本。

---

## 舵机相关

### 必须用 Python 控制，不能用 Shell

**症状：** Shell 脚本控制舵机时动作卡顿、不流畅。

**原因：** Shell 每步 fork bc/sleep 进程的开销导致延迟不可控。

**解决：** 所有舵机控制都用 Python + 余弦缓动：
```python
import math, time

def move_eased(pwm_path, start, end, steps=20, duration=0.2):
    for i in range(steps + 1):
        t = i / steps
        ease = (1 - math.cos(t * math.pi)) / 2
        duty = int(start + (end - start) * ease)
        with open(f"{pwm_path}/duty_cycle", "w") as f:
            f.write(str(duty))
        time.sleep(duration / steps)
```

**铁律：**
- 每个动作至少 12~25 步插值
- 必须余弦缓动（cosine ease-in-out）
- 禁止单步跳变超过 300000ns
- 参考实现：`scripts/dance.py`

---

## 模型相关

### sherpa-onnx API 兼容性

- `OfflineRecognizer` 要用工厂方法 `from_sense_voice()`，不能直接传 config
- `OfflineSpeakerDiarizationResult` 在 1.12.30 不能直接迭代，需调 `result.sort_by_start_time()` 返回 list
- 每个 segment 有 `.speaker` / `.start` / `.end` / `.text` 属性

### 模型下载慢

GitHub 在国内下载很慢（~700KB/s），优先用 HuggingFace 镜像：
- `https://hf-mirror.com/` — 国内镜像

### pip 安装慢

用清华镜像：
```bash
pip install -i https://pypi.tuna.tsinghua.edu.cn/simple 包名
```

---

## 摄像头相关

### MIPI 摄像头不是 V4L2

RDK X5 的 MIPI 摄像头通过 VIN/ISP API 访问，不是标准 V4L2。

使用 hobot_vio 的 `libsrcampy.Camera` 拍照：
```python
from hobot_vio import libsrcampy
cam = libsrcampy.Camera()
cam.open_cam(0, 1, 30, 1920, 1080)
# 输出 NV12 格式，需要 OpenCV 转 BGR
```

设备节点：`/dev/vin0_cap` ~ `/dev/vin3_cap`

---

## OpenClaw 相关

### 上下文窗口不要设太大

如果用第三方 API 代理，contextWindow 不要盲目设最大值。代理可能处理不了大上下文，会导致诡异的认证错误（如 `invalid_grant`）。

建议：contextWindow 不超过 200000，关闭 context1m。

### 自动压缩

压缩在 `contextTokens > contextWindow - reserveTokens` 时触发。如果 contextWindow 设太大，压缩永远不会触发，上下文无限膨胀直到出错。

---

## 系统相关

### pyaudio 装不了

RDK X5 系统没有 `portaudio19-dev`，pyaudio 编译会失败。

替代方案：用 `subprocess.Popen` 跑 `arecord`，从 stdout 读取 PCM 数据。

### 后台任务超时

长时间运行的命令要注意 timeout 设置，否则会被 SIGTERM 杀掉。

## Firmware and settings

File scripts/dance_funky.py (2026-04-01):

#!/usr/bin/env python3
"""Funky Robot Dance - 节奏感强的新舞蹈，融合抖动、画圈、甩头"""
import time
import math
import os

PWM_YAW = "/sys/class/pwm/pwmchip0/pwm0"
PWM_PITCH = "/sys/class/pwm/pwmchip0/pwm1"
CENTER = 1500000
YAW_RANGE = 300000   # 安全行程
PITCH_RANGE = 200000

def init_pwm():
    for ch in (0, 1):
        base = f"/sys/class/pwm/pwmchip0/pwm{ch}"
        if not os.path.isdir(base):
            with open("/sys/class/pwm/pwmchip0/export", "w") as f:
                f.write(str(ch))
        for name, val in [("period", "20000000"), ("duty_cycle", str(CENTER)), ("enable", "1")]:
            try:
                with open(f"{base}/{name}", "w") as f:
                    f.write(val)
            except OSError:
                pass

def set_servo(pwm_path, duty):
    duty = max(500000, min(2500000, int(duty)))
    with open(f"{pwm_path}/duty_cycle", "w") as f:
        f.write(str(duty))

def ease(t):
    return (1 - math.cos(t * math.pi)) / 2

def move(pwm_path, start, end, duration=0.2, steps=15):
    dt = duration / steps
    for i in range(1, steps + 1):
        t = i / steps
        pos = start + (end - start) * ease(t)
        set_servo(pwm_path, pos)
        time.sleep(dt)

def move_both(yaw_start, yaw_end, pitch_start, pitch_end, duration=0.2, steps=15):
    """同时移动两个舵机"""
    dt = duration / steps
    for i in range(1, steps + 1):
        t = i / steps
        e = ease(t)
        set_servo(PWM_YAW, yaw_start + (yaw_end - yaw_start) * e)
        set_servo(PWM_PITCH, pitch_start + (pitch_end - pitch_start) * e)
        time.sleep(dt)

def get_pos(pwm_path):
    """读取当前 duty_cycle"""
    with open(f"{pwm_path}/duty_cycle") as f:
        return int(f.read().strip())

# ===== 动作库 =====

def head_circle(radius_yaw=200000, radius_pitch=150000, duration=1.0, steps=40):
    """画圈 - 头部绕一个椭圆"""
    dt = duration / steps
    cy, cp = get_pos(PWM_YAW), get_pos(PWM_PITCH)
    for i in range(steps + 1):
        angle = 2 * math.pi * i / steps
        yaw = cy + radius_yaw * math.sin(angle)
        pitch = cp + radius_pitch * math.cos(angle)
        set_servo(PWM_YAW, yaw)
        set_servo(PWM_PITCH, pitch)
        time.sleep(dt)

def head_figure8(radius_yaw=200000, radius_pitch=120000, duration=1.5, steps=50):
    """8字摇摆"""
    dt = duration / steps
    for i in range(steps + 1):
        t = i / steps
        angle = 2 * math.pi * t
        yaw = CENTER + radius_yaw * math.sin(angle)
        pitch = CENTER + radius_pitch * math.sin(2 * angle)
        set_servo(PWM_YAW, yaw)
        set_servo(PWM_PITCH, pitch)
        time.sleep(dt)

def quick_tilt(direction=1, amp=150000, duration=0.12, steps=12):
    """快速歪头 - direction: 1=右歪, -1=左歪（用 yaw 模拟）"""
    cy = get_pos(PWM_YAW)
    target = cy + direction * amp
    move(PWM_YAW, cy, target, duration, steps)
    time.sleep(0.03)
    move(PWM_YAW, target, cy, duration, steps)

def shimmy(times=4, amp=120000, period=0.12):
    """快速左右抖动"""
    for i in range(times):
        d = 1 if i % 2 == 0 else -1
        move(PWM_YAW, CENTER - d * amp, CENTER + d * amp, duration=period, steps=10)
    move(PWM_YAW, get_pos(PWM_YAW), CENTER, duration=0.1, steps=8)

def slow_scan(duration=0.8):
    """慢速扫视 - 像在环顾四周"""
    move(PWM_YAW, CENTER, CENTER - YAW_RANGE, duration=duration * 0.4, steps=20)
    time.sleep(0.1)
    move(PWM_YAW, CENTER - YAW_RANGE, CENTER + YAW_RANGE, duration=duration * 0.6, steps=25)
    time.sleep(0.1)
    move(PWM_YAW, CENTER + YAW_RANGE, CENTER, duration=duration * 0.3, steps=15)

def double_take():
    """双重回头 - 假装看到什么吓一跳"""
    # 先慢慢转右
    move(PWM_YAW, CENTER, CENTER + 200000, duration=0.3, steps=15)
    time.sleep(0.15)
    # 快速甩回左
    move(PWM_YAW, CENTER + 200000, CENTER - 250000, duration=0.1, steps=12)
    time.sleep(0.05)
    # 快速甩回右
    move(PWM_YAW, CENTER - 250000, CENTER + 200000, duration=0.1, steps=12)
    # 停顿（震惊状）
    time.sleep(0.2)
    # 慢慢回中
    move(PWM_YAW, CENTER + 200000, CENTER, duration=0.25, steps=15)

def groove_nod(times=3, speed=1.0):
    """律动点头 - 带节奏感的点头，幅度递减"""
    for i in range(times):
        amp = int(PITCH_RANGE * (1.0 - i * 0.2))
        d = 0.12 / speed
        move(PWM_PITCH, CENTER, CENTER - amp, duration=d, steps=12)
        move(PWM_PITCH, CENTER - amp, CENTER, duration=d * 0.7, steps=10)
        time.sleep(0.02)

def sway_groove(cycles=2, speed=1.0):
    """摇摆律动 - yaw 大幅摆 + pitch 小律动同步"""
    amp_y = 250000
    amp_p = 100000
    period = 0.5 / speed
    steps = 20
    for c in range(cycles):
        d = 1 if c % 2 == 0 else -1
        dt = period / steps
        for i in range(1, steps + 1):
            t = i / steps
            e = ease(t)
            yaw = CENTER + d * amp_y * (2 * e - 1) if c > 0 else CENTER + d * amp_y * e
            pitch = CENTER + amp_p * math.sin(t * math.pi * 2)
            set_servo(PWM_YAW, yaw)
            set_servo(PWM_PITCH, pitch)
            time.sleep(dt)

def dramatic_bow():
    """戏剧性鞠躬"""
    # 先仰头
    move(PWM_PITCH, CENTER, CENTER + PITCH_RANGE, duration=0.2, steps=15)
    time.sleep(0.15)
    # 快速低头鞠躬
    move(PWM_PITCH, CENTER + PITCH_RANGE, CENTER - PITCH_RANGE, duration=0.18, steps=15)
    time.sleep(0.3)
    # 优雅回正
    move(PWM_PITCH, CENTER - PITCH_RANGE, CENTER, duration=0.3, steps=18)

# ===== 编舞 =====

def dance():
    init_pwm()
    set_servo(PWM_YAW, CENTER)
    set_servo(PWM_PITCH, CENTER)
    time.sleep(0.3)

    print("Funky Dance Start!")

    # === 第一段：开场 - 环顾+歪头（好奇地看周围） ===
    slow_scan(duration=0.8)
    time.sleep(0.1)
    quick_tilt(1)
    time.sleep(0.1)
    quick_tilt(-1)
    time.sleep(0.2)

    # === 第二段：律动 - 点头+摇摆（找到节奏了） ===
    groove_nod(times=4, speed=1.2)
    time.sleep(0.1)
    sway_groove(cycles=3, speed=1.3)
    time.sleep(0.1)

    # === 第三段：加速 - 快速抖动+画圈（嗨起来） ===
    shimmy(times=6, amp=150000, period=0.1)
    time.sleep(0.1)
    head_circle(radius_yaw=220000, radius_pitch=150000, duration=0.8, steps=35)
    time.sleep(0.05)
    head_circle(radius_yaw=180000, radius_pitch=120000, duration=0.6, steps=30)
    time.sleep(0.1)

    # === 第四段：高潮 - 8字+甩头（全力输出） ===
    head_figure8(radius_yaw=250000, radius_pitch=150000, duration=1.2, steps=45)
    time.sleep(0.1)
    double_take()
    time.sleep(0.1)
    shimmy(times=8, amp=180000, period=0.08)
    time.sleep(0.1)

    # === 第五段：收尾 - 慢摇+鞠躬 ===
    sway_groove(cycles=2, speed=0.8)
    time.sleep(0.2)
    dramatic_bow()
    time.sleep(0.1)

    # 回中
    move_both(get_pos(PWM_YAW), CENTER, get_pos(PWM_PITCH), CENTER, duration=0.3, steps=18)
    time.sleep(0.2)

    print("Funky Dance Done!")

if __name__ == "__main__":
    dance()

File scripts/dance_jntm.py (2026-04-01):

#!/usr/bin/env python3
"""鸡你太美 v3 - 严格节奏控制版
每个动作严格在分配的拍数内完成，避免时间漂移
"""
import time
import math
import os
import threading
import subprocess

PWM_YAW = "/sys/class/pwm/pwmchip0/pwm0"
PWM_PITCH = "/sys/class/pwm/pwmchip0/pwm1"
CENTER = 1500000
STEP = 100000

L = CENTER - STEP * 3
R = CENTER + STEP * 3
L2 = CENTER - STEP * 2
R2 = CENTER + STEP * 2
UP = CENTER - STEP * 2
DN = CENTER + STEP * 2
C = CENTER

BPM = 130.4
BEAT = 60.0 / BPM
MUSIC = os.path.join(os.path.dirname(os.path.abspath(__file__)), "..", "media", "jntm_real.wav")

def init_pwm():
    for ch in (0, 1):
        base = f"/sys/class/pwm/pwmchip0/pwm{ch}"
        if not os.path.isdir(base):
            with open("/sys/class/pwm/pwmchip0/export", "w") as f:
                f.write(str(ch))
        for name, val in [("period", "20000000"), ("duty_cycle", str(CENTER)), ("enable", "1")]:
            try:
                with open(f"{base}/{name}", "w") as f:
                    f.write(val)
            except OSError:
                pass

def set_servo(pwm_path, duty):
    duty = max(500000, min(2500000, int(duty)))
    with open(f"{pwm_path}/duty_cycle", "w") as f:
        f.write(str(duty))

def ease(t):
    return (1 - math.cos(t * math.pi)) / 2

def move2(y_start, y_end, p_start, p_end, dur, steps=15):
    """双轴同步移动，严格控制总时长"""
    dt = dur / steps
    for i in range(1, steps + 1):
        e = ease(i / steps)
        set_servo(PWM_YAW, y_start + (y_end - y_start) * e)
        set_servo(PWM_PITCH, p_start + (p_end - p_start) * e)
        time.sleep(dt)

def at_beat(t0, beat_num):
    """等到指定拍数的时刻"""
    target = t0 + beat_num * BEAT
    delay = target - time.monotonic()
    if delay > 0:
        time.sleep(delay)

def play_music():
    subprocess.run(["aplay", "-D", "plughw:0,0", MUSIC],
                   stdout=subprocess.DEVNULL, stderr=subprocess.DEVNULL)

def choreography(t0):
    """完整编舞 - 每个动作严格卡拍"""
    
    # 拍0: 准备
    at_beat(t0, 0)
    move2(C, C, C, C, BEAT * 0.5, 10)
    
    # 拍3-10: 说唱开头 - 左右律动
    for i in range(4):
        b = 3 + i * 2
        at_beat(t0, b)
        ty = L2 if i % 2 == 0 else R2
        move2(C if i == 0 else (R2 if i % 2 == 0 else L2), ty, C, DN, BEAT * 0.8, 12)
        at_beat(t0, b + 1)
        move2(ty, C, DN, C, BEAT * 0.8, 12)
    
    # 拍11-22: 运球段 - 快速左右+点头
    for i in range(12):
        b = 11 + i * 0.5
        at_beat(t0, b)
        ty = L2 if i % 2 == 0 else R2
        tp = DN if i % 4 < 2 else C
        prev_y = R2 if i % 2 == 0 else L2
        prev_p = C if i % 4 < 2 else DN
        move2(prev_y if i > 0 else C, ty, prev_p if i > 0 else C, tp, BEAT * 0.4, 8)
    
    # 拍23-30: 波浪段
    wave_seq = [(L, DN), (L2, C), (C, UP), (R2, C), (R, DN), (R2, C), (C, UP), (L2, C)]
    for i, (y, p) in enumerate(wave_seq):
        b = 23 + i
        at_beat(t0, b)
        prev = wave_seq[i-1] if i > 0 else (C, C)
        move2(prev[0], y, prev[1], p, BEAT * 0.8, 12)
    
    # 拍31-34: 转身
    at_beat(t0, 31)
    move2(C, L, C, C, BEAT * 0.8, 10)
    at_beat(t0, 32)
    move2(L, R, C, C, BEAT * 1.5, 15)
    at_beat(t0, 34)
    move2(R, C, C, C, BEAT * 0.8, 10)
    
    # 拍35-42: 快速摇头
    for i in range(16):
        b = 35 + i * 0.5
        at_beat(t0, b)
        ty = L if i % 2 == 0 else R
        move2(R if i % 2 == 0 else L, ty, C, C, BEAT * 0.4, 8)
    
    # 拍43-50: 指人动作连击
    for i in range(4):
        b = 43 + i * 2
        at_beat(t0, b)
        move2(C, C, C, DN + STEP, BEAT * 0.6, 10)
        at_beat(t0, b + 1)
        move2(C, C, DN + STEP, C, BEAT * 0.6, 10)
    
    # 拍51-58: 波浪连击
    for i, (y, p) in enumerate(wave_seq):
        b = 51 + i
        at_beat(t0, b)
        prev = wave_seq[i-1] if i > 0 else (C, C)
        move2(prev[0], y, prev[1], p, BEAT * 0.8, 12)
    
    # 拍59-66: 疯狂左右甩
    for i in range(16):
        b = 59 + i * 0.5
        at_beat(t0, b)
        ty = L if i % 2 == 0 else R
        tp = DN if i % 4 < 2 else UP
        prev_y = R if i % 2 == 0 else L
        prev_p = UP if i % 4 < 2 else DN
        move2(prev_y if i > 0 else C, ty, prev_p if i > 0 else C, tp, BEAT * 0.35, 7)
    
    # 拍67-74: 再来一轮波浪
    for i, (y, p) in enumerate(wave_seq):
        b = 67 + i
        at_beat(t0, b)
        prev = wave_seq[i-1] if i > 0 else (C, C)
        move2(prev[0], y, prev[1], p, BEAT * 0.8, 12)
    
    # 拍75-82: 极速摇头
    for i in range(32):
        b = 75 + i * 0.25
        at_beat(t0, b)
        ty = L2 if i % 2 == 0 else R2
        move2(R2 if i % 2 == 0 else L2, ty, C, C, BEAT * 0.2, 5)
    
    # 拍83-90: 大幅横扫
    for i in range(8):
        b = 83 + i
        at_beat(t0, b)
        ty = L if i % 2 == 0 else R
        move2(R if i % 2 == 0 else L, ty, C, C, BEAT * 0.8, 12)
    
    # 拍91-98: 上下起伏
    for i in range(8):
        b = 91 + i
        at_beat(t0, b)
        tp = DN if i % 2 == 0 else UP
        move2(C, C, UP if i % 2 == 0 else DN, tp, BEAT * 0.8, 12)
    
    # 拍99-106: 组合动作 - 左右+上下
    for i in range(8):
        b = 99 + i
        at_beat(t0, b)
        ty = L if i % 2 == 0 else R
        tp = DN if i % 2 == 0 else UP
        prev_y = R if i % 2 == 0 else L
        prev_p = UP if i % 2 == 0 else DN
        move2(prev_y if i > 0 else C, ty, prev_p if i > 0 else C, tp, BEAT * 0.8, 12)
    
    # 拍107-114: 最后波浪
    for i, (y, p) in enumerate(wave_seq):
        b = 107 + i
        at_beat(t0, b)
        prev = wave_seq[i-1] if i > 0 else (C, C)
        move2(prev[0], y, prev[1], p, BEAT * 0.8, 12)
    
    # 拍115-120: 慢速大幅摇摆
    at_beat(t0, 115)
    move2(C, L, C, C, BEAT * 1.5, 15)
    at_beat(t0, 117)
    move2(L, R, C, C, BEAT * 2.0, 18)
    at_beat(t0, 120)
    move2(R, C, C, C, BEAT * 1.5, 15)
    
    # 拍122-128: 鞠躬结束
    at_beat(t0, 122)
    move2(C, C, C, DN + STEP * 2, BEAT * 2.0, 20)
    at_beat(t0, 126)
    move2(C, C, DN + STEP * 2, C, BEAT * 2.0, 20)
    
    set_servo(PWM_YAW, C)
    set_servo(PWM_PITCH, C)

def main():
    init_pwm()
    set_servo(PWM_YAW, CENTER)
    set_servo(PWM_PITCH, CENTER)
    
    print("🐔 鸡你太美 v3 - 严格节奏版")
    time.sleep(0.5)
    
    audio_thread = threading.Thread(target=play_music, daemon=True)
    t0 = time.monotonic()
    audio_thread.start()
    
    print("🎵 开始表演！")
    choreography(t0)
    
    audio_thread.join(timeout=5)
    
    set_servo(PWM_YAW, CENTER)
    set_servo(PWM_PITCH, CENTER)
    
    print("✨ 表演结束！")

if __name__ == "__main__":
    main()

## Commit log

2026-04-01 fix: update GitHub username to RDK550W
    [dance.py, dance_funky.py, dance_jntm.py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]
2026-04-01 restructure: flatten layout, add DEPLOY.md for agent auto-deploy
    - MOSS = 流浪地球的 MOSS，不是缩写
    - USB 音频模块是麦克风+扬声器一体
    - 扁平化目录结构：去掉 software/ 层级
    - 新增 DEPLOY.md：Agent 可直接按步骤自动部署
    - 更新 install.sh 路径适配新结构
2026-04-01 add: 3D model files (SolidWorks 2024) for enclosure and pan-tilt mount
    - 装配体 + 标准件 + 零件库（共 20 个文件，21MB）
    - P06 主体后壳有 X5 专用版
    - 含安装卡扣、顶座、机械臂、支座等全部零件
    [P00_安装卡扣.SLDPRT, P01_顶座.SLDPRT, P02_顶座上盖.SLDPRT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]
2026-04-01 add: knowledge-base.md - technical experience from MEMORY.md
    - 摄像头、语音系统、舵机控制的详细技术参数
    - ALSA 配置经验、sherpa-onnx API 注意事项
    - 音乐同步舞蹈编排方法论
    - BPU 模型资产清单（系统自带的全部预转换模型）
    - 排查经验和常见陷阱
    - 去除了所有个人信息，只保留通用技术内容
2026-04-01 add: MEMORY.md.template - factory memory with technical experience
    从实际运行经验中提取的出厂记忆，让新 Agent 不用从零踩坑：
    - 摄像头、语音、舵机、音乐同步的完整技术参数
    - ALSA/sherpa-onnx/PWM 的关键配置和注意事项
    - BPU 模型资产清单
    - 所有踩过的坑和教训
    - 已去除个人信息
2026-04-01 fix: audit and cleanup
    - 修复音效文件位置：从 sounds/ 移到 voice-assistant/ 根目录，与代码路径一致
    - 补上缺失的 wake_response.wav
    - 消除所有硬编码绝对路径（snap.py, camera_test.py, dance_jntm.py）
    - shell 脚本添加执行权限
    - install.sh 适配音效文件新位置
    [dance_jntm.py]
